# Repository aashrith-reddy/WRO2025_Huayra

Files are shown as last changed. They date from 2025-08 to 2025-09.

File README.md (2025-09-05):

## Team Members  
• Aashrith Chittamuru \
• Daksh Singh  \
• Vatsal Abrol 

**Coach**: \
• Mr.Kailash *(Roboprenr – Bangalore, India)*  

---

## Introduction
The **WRO2025_Huayra** project is a submission for the World Robot Olympiad (WRO) 2025 under the Future Engineers category. This initiative challenges participants to design, build, and program a self-driving vehicle that can navigate a dynamic environment autonomously. The project integrates mechanical design, embedded systems, and software engineering to create a robust autonomous platform. \
This report outlines the technical architecture, design methodology, software implementation, and theoretical underpinnings of the vehicle developed by Team Huayra.

---

## Project / Bot Description 
Our robot features a **rigid metal chassis reinforced with precision 3D-printed components**, ensuring durability. At its core, a **Raspberry Pi 5** orchestrates real-time processing for **laser sensors, a camera module, and a servo-driven steering system**, enabling highly accurate navigation and control. Its **low ground clearance, inspired by Formula 1 engineering principles, enhances stability and downforce**, ensuring superior performance during high-speed maneuvers. Designed with precision and reliability this platform is built to excel in the **WRO Future Engineers competition**.

---

## Table of Contents 
• **models**: contains .stl design files of all the 3d printed parts \
• **others**: contains additional documentation, such as Raspberry Pi setup and terminal usage guides, to help prepare the vehicle for the competition. \
• **schemes**: contains all the schematic diagrams and illustrates the functioning of the components used in the project \
• **src**: contains code for all components which were programmed for this competition. It also contains the final code for the competition \
• **videos**: includes two videos of the bot functioning \
• **vehicle-photos**: contains 6 photos of the bot (front, back, left, right, top, bottom) \
• **team-photos**: contains 2 images of our team (1 formal and 1 funny)

---

## Hardware Components

| Component | Description |
|---|---|
| Arduino Uno | Microcontroller for low-level sensor interfacing and motor control |
| Raspberry Pi | High-level processing unit for decision-making and image processing |
| Ultrasonic Sensors | Distance measurement for obstacle detection |
| Servo Motors | Steering mechanism |
| DC Motors with Encoders | Drive system with feedback for speed and position |
| Li-ion Battery Pack | Power source with voltage regulation |

## Software Stack

•  *Arduino IDE*: Used to program the microcontroller \
•  *Python (on Raspberry Pi)*: Handles image recognition, path planning, and serial communication \
•  *OpenCV*: For visual input processing and object detection

---

## Serial Communication Protocol

The  SerialCommunicationArduino.ino  file implements a custom protocol to facilitate reliable data exchange between the Arduino and Raspberry Pi. Key features include:

•  Baud rate synchronization at 9600 bps \
•  Real-time sensor data transmission

This protocol ensures deterministic behavior and low-latency control, critical for autonomous navigation.

---

## Mechanical Design

The chassis and structural components were designed with our critical thinking abilities using metal plates and CAD software and fabricated using 3D printing. The car's design was inspired from the old F1 cars from the early 2000's where the real wheels were bigger size than the front wheels as the rear drving system was built higher in the rear of the car than the front. STL files in the repository’s  models  folder provide the geometry for:

•  Wheel mounts \
•  Sensor brackets \
•  Battery housing \
•  Modular frame connectors

The design prioritizes weight distribution, accessibility, and modularity for quick maintenance and upgrades.

---

## Circuit Schematics

The  schemes  folder contains detailed circuit diagrams illustrating the integration of sensors, actuators, and controllers. These schematics follow best practices in embedded system design:

•  Insulating the metal base plates with tape to avoid short-circuiting \
•  Integration between arduino and Raspberry Pi 5 \
•  Fuse protection for motor drivers

---

## Control Algorithms

•  **Open Challenge**: Ultrasonic sensors detect the walls (boundaries) and the arduino adjusts motor speed as and when the car is turning or going straight. \
•  **Obstacle Avoidance**: Camera reaches a specific area limit of the color due to which it turns. \
•  **Parking Algorithm**: Uses Ultrasonic sensor feedback and servo positioning to execute parallel parking.

---

## Conclusion

The WRO2025_Huayra project reflects our team’s dedication to combining mechanical design, electronics, and advanced software algorithms into a single autonomous vehicle capable of tackling the dynamic challenges of the WRO Future Engineers competition. By leveraging the strengths of both the Arduino Uno and Raspberry Pi 5, we achieved a balance between low-level real-time control and high-level decision-making. Our focus on rigid mechanical design, robust sensor integration, and modular architecture ensures that the vehicle is not only competition-ready but also adaptable for future improvements.

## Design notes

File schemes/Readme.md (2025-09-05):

# Schemes Folder – Electromechanical Diagrams

This folder contains all schematic diagrams and layout illustrations for the entire project.

## Files

Each file provides visual context for the hardware and wiring.
1. `Design.md`
2. `Differential_Gearbox.md`
3. `Parts_List.md`

## Attachments

1. `CircuitDiagram.png` – Wiring map of Pi 5, sensors, camera, servo, motor driver, and power system.
2. `FirstLayer.png` – First layer showing steering system, servo, motor, battery, and gearbox.
3. `SecondLayer.png` – Top layer with Pi 5, cooling, buck converter, TOF sensors, and camera mount.
4. `ChassisSide.png` – Side view showing low clearance, stacked layers, and component layout.
5. `DifferentialGearbox_functioning.png` – Diagram of torque split between rear wheels during turns.
6. `DifferentialGearbox_parts.png` – Labeled schematic of all differential gearbox components.

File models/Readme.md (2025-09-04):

# 3D Models

This folder contains all the **3D design files** used in the construction of our competition robot.  

## Contents
Below is a list of all 3D-printed files included in this folder:

- **CouplerForGearbox.stl** – 3D design of the **Coupler** which connects the **Wheels** and the **Differential Gearbox**  
- **DifferentialHolder.stl** – 3D design for the **Differential Gearbox Holder**

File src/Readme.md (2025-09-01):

# Software Documentation

This repository contains **all modular scripts** used to build the final code. Below is a **script-by-script feature list** for the entire project:

---

### camera.py
```bash
from picamera2 import Picamera2
import cv2, time

cam = Picamera2()
cam.configure(cam.create_preview_configuration(main={"format":"RGB888","size":(640,480)}))
cam.start(); time.sleep(0.5)

while True:
    f = cam.capture_array()
    cv2.imshow("Feed", f)
    if cv2.waitKey(1)&0xFF==ord('q'): break

cam.stop(); cv2.destroyAllWindows()
```

**1.	Imports required libraries** \
&nbsp;&nbsp;&nbsp;•	picamera2 to control Raspberry Pi Camera \
&nbsp;&nbsp;&nbsp;•	cv2 (OpenCV) to show frames in a window \
&nbsp;&nbsp;&nbsp;•	time for adding a small delay after starting the camera
```bash
from picamera2 import Picamera2
import cv2, time
```

**2.	Initializes the camera** \
&nbsp;&nbsp;&nbsp;•	Creates a Picamera2 object under the variable name cam. \
&nbsp;&nbsp;&nbsp;•	Configures it to output **640×480 frames** in **RGB888 format**.
```bash
cam = Picamera2()
cam.configure(cam.create_preview_configuration(main={"format":"RGB888","size":(640,480)}))
```
**3.	Starts the camera** \
&nbsp;&nbsp;&nbsp;•	Starts streaming frames. \
&nbsp;&nbsp;&nbsp;•	Waits 0.5 seconds to allow the sensor to stabilize.
```bash
cam.start(); time.sleep(0.5)
```
**4.	Main loop to display video** \
&nbsp;&nbsp;&nbsp;•	Displays them in a window titled “Feed”. \
&nbsp;&nbsp;&nbsp;•	Exits when the ‘q’ key is pressed.
```bash
while True:
    f = cam.capture_array()
    cv2.imshow("Feed", f)
    if cv2.waitKey(1)&0xFF==ord('q'): break
```
**5. Stops the camera** \
&nbsp;&nbsp;&nbsp;•	Stops the camera stream. \
&nbsp;&nbsp;&nbsp;•	Closes any OpenCV windows.
```bash
cam.stop(); cv2.destroyAllWindows()
```

---

### **TOFsensor.py**
```bash
import time
import board
import busio
from gpiozero import LED
from adafruit_vl53l0x import VL53L0X

xshut_pin = LED(17)
i2c = busio.I2C(board.SCL, board.SDA)
xshut_pin.off()
time.sleep(0.1)
xshut_pin.on()
time.sleep(0.1)
sensor = VL53L0X(i2c)

try:
    while True:
        distance = sensor.range /10
        print(f"Distance: {distance} cm")
        time.sleep(1)
except KeyboardInterrupt:
    print("Program stopped")
```

**1. Imports required libraries** \
&nbsp;&nbsp;&nbsp;•	time — used for adding short delays. \
&nbsp;&nbsp;&nbsp;•	board — maps Raspberry Pi pins (SCL, SDA, etc.) for I²C communication. \
&nbsp;&nbsp;&nbsp;•	busio.I2C — handles I²C protocol communication. \
&nbsp;&nbsp;&nbsp;•	gpiozero.LED — convenient way to control a GPIO pin as a simple on/off output (here, it’s used for XSHUT rather than an actual LED). \
&nbsp;&nbsp;&nbsp;•	adafruit_vl53l0x.VL53L0X — library to talk to the VL53L0X time-of-flight distance sensor.
```bash
import time
import board
import busio
from gpiozero import LED
from adafruit_vl53l0x import VL53L0X
```

**2. Hardware Setup** \
&nbsp;&nbsp;&nbsp;•	xshut_pin is GPIO17 configured as an output using gpiozero’s LED class. \
&nbsp;&nbsp;&nbsp;&nbsp;&nbsp;&nbsp;•	Even though it’s called LED, it’s just a digital output that can be turned on/off. \
&nbsp;&nbsp;&nbsp;&nbsp;&nbsp;&nbsp;•	This pin is connected to the XSHUT (shutdown) pin of the VL53L0X sensor. \
&nbsp;&nbsp;&nbsp;•	i2c = busio.I2C(board.SCL, board.SDA) sets up the I²C bus using the Pi’s hardware SCL and SDA pins.
```bash
xshut_pin = LED(17)
i2c = busio.I2C(board.SCL, board.SDA)
```

**3. Reset the sensor using XSHUT** \
&nbsp;&nbsp;&nbsp;•	xshut_pin.off() drives GPIO17 low due to which VL53L0X is held in reset (powered off). \
&nbsp;&nbsp;&nbsp;•	Wait 0.1 s for it to fully power down. \
&nbsp;&nbsp;&nbsp;•	xshut_pin.on() drives GPIO17 high due to which VL53L0X powers up again. \
&nbsp;&nbsp;&nbsp;•	Wait another 0.1 s for the sensor to initialize. \ \

&nbsp;&nbsp;&nbsp;This reset sequence ensures the sensor is in a clean state, and is especially useful when you have multiple sensors on the same I²C bus &nbsp;&nbsp;&nbsp;(you can power them up one at a time and give them unique addresses).
```bash
xshut_pin.off()
time.sleep(0.1)
xshut_pin.on()
time.sleep(0.1)
```

**4. Create the sensor object** \
&nbsp;&nbsp;&nbsp;•	Initializes the Adafruit VL53L0X driver on the I²C bus. \
&nbsp;&nbsp;&nbsp;•	The library automatically uses the default address 0x29 unless you change it.
```bash
sensor = VL53L0X(i2c)
```

**5. Main Loop** \
&nbsp;&nbsp;&nbsp;•	sensor.range returns distance in millimeters (mm). \
&nbsp;&nbsp;&nbsp;•	Dividing by 10 converts to centimeters (cm). \
&nbsp;&nbsp;&nbsp;•	Prints out the distance every 1 second.
```bash
try:
    while True:
        distance = sensor.range / 10
        print(f"Distance: {distance} cm")
        time.sleep(1)
```

**6. Exit** \
&nbsp;&nbsp;&nbsp;•	If you press Ctrl + C, the loop ends and prints a message.
```bash
except KeyboardInterrupt:
    print("Program stopped")
```

---

### **Steering.py**
```bash
from rpi_hardware_pwm import HardwarePWM
from time import sleep

pwm = HardwarePWM(pwm_channel=0, hz=50, chip=0)
pwm.start(5)

try:
    while True:
        pwm.change_duty_cycle(5)
        sleep(2)
        pwm.change_duty_cycle(7.5)
        sleep(2)
        pwm.change_duty_cycle(9.7)
        sleep(2)
        pwm.change_duty_cycle(7.5)
        sleep(2)

except KeyboardInterrupt:
    pwm.stop()
```
**1. Imports Required Libraries** \
&nbsp;&nbsp;&nbsp;•	rpi_hardware_pwm.HardwarePWM lets you control the Pi’s built-in hardware PWM channels. Hardware PWM is more stable and jitter-&nbsp;&nbsp;&nbsp;free than software PWM (like in RPi.GPIO), which is especially important for servos. \
&nbsp;&nbsp;&nbsp;•	sleep() pauses the program for a specified time in seconds.
```bash
from rpi_hardware_pwm import HardwarePWM
from time import sleep
```
**2. Create PWM object** \
&nbsp;&nbsp;&nbsp;•	pwm_channel=0 — uses hardware PWM channel 0 (the Pi has two: 0 and 1). \
&nbsp;&nbsp;&nbsp;•	hz=50 — sets frequency to 50 Hz (period = 20 ms), standard for servo motors. \
&nbsp;&nbsp;&nbsp;•	chip=0 — refers to /sys/class/pwm/pwmchip0, the first hardware PWM controller on the Pi.
```bash
pwm = HardwarePWM(pwm_channel=0, hz=50, chip=0)
```
**3. Start PWM with 5% duty cycle** \
&nbsp;&nbsp;&nbsp;•  This enables PWM output on that channel with a duty cycle of 5% (i.e., the signal is HIGH for 1 ms and LOW for 19 ms, since 20 ms &nbsp;&nbsp;&nbsp;period × 5% = 1 ms). \
&nbsp;&nbsp;&nbsp;•	For a hobby servo: \
&nbsp;&nbsp;&nbsp;&nbsp;&nbsp;&nbsp;•	~5% → far left position (~0°) \
&nbsp;&nbsp;&nbsp;&nbsp;&nbsp;&nbsp;•	~7.5% → center (~90°) \
&nbsp;&nbsp;&nbsp;&nbsp;&nbsp;&nbsp;•	~10% → far right (~180°)
```bash
pwm.start(5)
```
**4. Main Loop** \
&nbsp;&nbsp;&nbsp;•	5% → servo moves to left position \
&nbsp;&nbsp;&nbsp;•	7.5% → servo centers \
&nbsp;&nbsp;&nbsp;•	9.7% → servo moves to right position \
&nbsp;&nbsp;&nbsp;•	7.5% → servo centers again

**5. Exit** \
&nbsp;&nbsp;&nbsp;•	When you press Ctrl + C, the program exits the loop. \
&nbsp;&nbsp;&nbsp;•	pwm.stop() disables PWM output so the pin no longer outputs a PWM signal.
```bash
except KeyboardInterrupt:
    pwm.stop()
```

---

### **MotorDriver.py**
```bash
from gpiozero import DigitalOutputDevice
from rpi_hardware_pwm import HardwarePWM
from time import sleep

direction = DigitalOutputDevice(17)
pwm = HardwarePWM(pwm_channel=1, hz=18000, chip=0)

try:
    direction.value = 1
    pwm.start(30)
    print("Motor running forward at 30%...")
    sleep(5)

    pwm.stop()
    print("Motor stopped.")
    sleep(1)

    direction.value = 0
    pwm.start(30)
    print("Motor running backward at 30%...")
    sleep(5)

    pwm.stop()
    print("Motor stopped.")

except KeyboardInterrupt:
    print("Interrupted by user.")
    pwm.stop()
```
**1. Imports required Libraries** \
&nbsp;&nbsp;&nbsp;•	DigitalOutputDevice (gpiozero) — lets you easily set a GPIO pin HIGH or LOW to control directio \
&nbsp;&nbsp;&nbsp;•	HardwarePWM (rpi_hardware_pwm) — generates a very stable PWM signal directly using the Pi’s hardware \
&nbsp;&nbsp;&nbsp;•	sleep: Used to pause execution for a given number of seconds.
```bash
from gpiozero import DigitalOutputDevice
from rpi_hardware_pwm import HardwarePWM
from time import sleep
```
**2. Hardware setup** \
&nbsp;&nbsp;&nbsp;•	direction → GPIO17 controls the motor’s rotation direction. \
&nbsp;&nbsp;&nbsp;•	pwm → hardware PWM on channel 1 at 18 kHz frequency. \
&nbsp;&nbsp;&nbsp;&nbsp;&nbsp;&nbsp;•	18 kHz is above human hearing which means that no audible whining from the motor would be heard.
```bash
direction = DigitalOutputDevice(17)
pwm = HardwarePWM(pwm_channel=1, hz=18000, chip=0)
```
**3. Main Loop** \
&nbsp;&nbsp;&nbsp;•	direction.value: \
&nbsp;&nbsp;&nbsp;&nbsp;&nbsp;&nbsp;• =1 → sets GPIO17 HIGH which makes the motor driver rotate the motor forward. \
&nbsp;&nbsp;&nbsp;&nbsp;&nbsp;&nbsp;• =0 → sets GPIO17 LOW which makes the motor driver rotate the motor backward. \
&nbsp;&nbsp;&nbsp;•	pwm.start(30) → starts PWM with 30% duty cycle, meaning the motor gets ~30% of its speed. \
&nbsp;&nbsp;&nbsp;•	sleep() → waits for an amount of time

**4. Exit** \
&nbsp;&nbsp;&nbsp;•	If you press Ctrl + C, the program exits and ensures PWM is stopped so the motor doesn’t keep running unexpectedly.
```bash
except KeyboardInterrupt:
    print("Interrupted by user.")
    pwm.stop()
```
---

### **ColorDetection.py**
```bash
import cv2
import numpy as np
from picamera2 import Picamera2

COLOR_RANGES = {
    "orange":  (np.array([5, 120, 120]),  np.array([22, 255, 255])),
    "blue":    (np.array([95, 80, 60]),   np.array([125, 255, 255])),
    "red1":    (np.array([0, 150, 80]),   np.array([10, 255, 255])),
    "red2":    (np.array([170,150,80]),   np.array([179,255,255])),
    "green":   (np.array([40, 80, 80]),   np.array([85, 255, 255])),
    "magenta": (np.array([140, 80, 80]),  np.array([170, 255, 255]))
}

picam2 = Picamera2()
config = picam2.create_preview_configuration(main={"size": (640, 480)})
picam2.configure(config)
picam2.start()

print("Press 'q' to quit")

while True:
    frame = picam2.capture_array()
    hsv = cv2.cvtColor(frame, cv2.COLOR_BGR2HSV)
    
    # Loop through colors and detect
    for color, (lower, upper) in COLOR_RANGES.items():
        if color == "red1":  
            # Special handling for red (two ranges)
            mask1 = cv2.inRange(hsv, COLOR_RANGES["red1"][0], COLOR_RANGES["red1"][1])
            mask2 = cv2.inRange(hsv, COLOR_RANGES["red2"][0], COLOR_RANGES["red2"][1])
            mask = cv2.bitwise_or(mask1, mask2)
            display_color = (0, 0, 255)
            label = "red"
        else:
            mask = cv2.inRange(hsv, lower, upper)
            if color == "orange":  display_color = (0, 140, 255)
            elif color == "blue": display_color = (255, 0, 0)
            elif color == "green": display_color = (0, 255, 0)
            elif color == "magenta": display_color = (255, 0, 255)
            label = color

        contours, _ = cv2.findContours(mask, cv2.RETR_EXTERNAL, cv2.CHAIN_APPROX_SIMPLE)
        for cnt in contours:
            area = cv2.contourArea(cnt)
            if area > 1000:  # filter noise
                x, y, w, h = cv2.boundingRect(cnt)
                cv2.rectangle(frame, (x, y), (x+w, y+h), display_color, 2)
                cv2.putText(frame, label, (x, y-10), cv2.FONT_HERSHEY_SIMPLEX, 0.6, display_color, 2)
    
    cv2.imshow("Color Detection", frame)
    if cv2.waitKey(1) & 0xFF == ord('q'):
        break

cv2.destroyAllWindows()
picam2.stop()
```
**1. Import required Libraries** \
&nbsp;&nbsp;&nbsp;•	cv2: for image processing, drawing, masking, contour detection, showing live video. \
&nbsp;&nbsp;&nbsp;•	numpy: for array operations and defining HSV color bounds. \
&nbsp;&nbsp;&nbsp;•	picamera2: to access Raspberry Pi Camera v1.3 on Raspberry Pi 5.
```bash
import cv2
import numpy as np
from picamera2 import Picamera2
```
**2. Define Color Ranges (in HSV)** \
&nbsp;&nbsp;&nbsp;•	A dictionary COLOR_RANGES stores lower and upper HSV limits for orange, blue, red, green, and magenta. \
&nbsp;&nbsp;&nbsp;•	Red uses two separate ranges (red1 and red2) because red appears at both ends of the hue scale. \
&nbsp;&nbsp;&nbsp;•	These ranges allow easy color filtering using OpenCV’s cv2.inRange() function. \

**3. Initialize the Raspberry Pi Camera** \
&nbsp;&nbsp;&nbsp;•	Create a Picamera2() instance. \
&nbsp;&nbsp;&nbsp;•	Configure it for preview at 640×480 resolution. \
&nbsp;&nbsp;&nbsp;•	Start the camera so frames can be captured continuously.
```bash
picam2 = Picamera2()
config = picam2.create_preview_configuration(main={"size": (640, 480)})
picam2.configure(config)
picam2.start()
print("Press 'q' to quit")
```
**4. Main Loop** \
&nbsp;&nbsp;&nbsp;• Capture each frame, convert it to HSV, detect colors, and draw bounding boxes \
&nbsp;&nbsp;&nbsp;•	inRange() creates a binary mask for each color. \
&nbsp;&nbsp;&nbsp;•	findContours() locates regions of that color. \
&nbsp;&nbsp;&nbsp;•	Bounding boxes and labels are drawn only if the blob is large enough (area > 1000).

**5. Display Results** \
&nbsp;&nbsp;&nbsp;•	imshow() opens a live video feed with detection boxes. \
&nbsp;&nbsp;&nbsp;•	waitKey(1) allows OpenCV to update the display and listen for keyboard input. \
&nbsp;&nbsp;&nbsp;•	Exits loop when q is pressed.
```bash
    cv2.imshow("Color Detection", frame)
    if cv2.waitKey(1) & 0xFF == ord('q'):
        break
```
**6. Cleanup** \
&nbsp;&nbsp;&nbsp;•	destroyAllWindows() closes any OpenCV GUI windows. \
&nbsp;&nbsp;&nbsp;•	stop() shuts down the Pi camera properly.
```bash
cv2.destroyAllWindows()
picam2.stop()
```
---

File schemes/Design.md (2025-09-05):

# Chassis and Structural Layout

The foundation of the robot is a **metal base plate**, which provides mechanical strength and rigidity to support all mounted subsystems. The bottom layer of this base is equipped with the **Steering System**, actuated by a **Servo motor** that precisely controls the angular orientation of the front wheels. This servo-based control enables accurate navigation and cornering, critical for path-following algorithms and obstacle avoidance. Positioned on the same bottom layer, the **motor** is connected to a **differential gearbox**, which is securely held in place by a **3D-printed holder**. The rear wheels are also attached to the gearbox using **3D-printed couplers**. Additionally, a **3D-printed camera stand** is placed on this bottom layer, located between the motor and the steering system. The 3D-models are present in the `models` folder.

A key design consideration is the robot’s **minimal ground clearance**, achieved through a **low-profile chassis configuration inspired by Formula 1 car engineering**. This design enhances **aerodynamic downforce**, improving **wheel-to-ground contact** during motion, resulting in significantly **increased stability**, particularly at higher speeds or during sharp directional transitions.

---
# Drive Mechanism

Located on the bottom layer, the motor serves as the **primary source** of **mechanical power** for the drivetrain. Its output shaft is **mechanically coupled to a differential gearbox**, held by a **3D-printed mount**, which splits torque between the two rear wheels. This allows each wheel to rotate at different speeds while receiving power from the same motor, a critical feature during turning maneuvers where inner and outer wheels travel different distances. The wheels are connected to the gearbox using **3D-printed couplers**, ensuring precise alignment and durability.

More about the differential gearbox is present in `Differential_Gearbox.md`.

---
# Battery Placement and Power Routing

On the bottom layer, four metallic spacers are mounted vertically at the rear corners and center, forming a platform to support a small metal plate on the next layer. This upper layer houses the **2500mAh Battery**, positioned to remain protected and thermally isolated from heat-generating components. The **wiring from the battery** is routed to the upper layer, which connects to the **motor as well as the arduino**. The battery efficiently regulates and distributes electrical power to the **Arduino Uno** and **motor**. The **Raspberry Pi 5** is powered by a **lithium ion 10000 Mah power bank** and are also placed on this upper layer, ensuring a compact and organized power management system.

---
# Sensor Configuration

The robot features a **three-sensor array** of **Ultrasonic sensors**, designed to optimize spatial awareness and real-time environmental perception. One sensor faces **directly forward**, providing accurate distance measurements along the primary axis of movement. The other two sensors are mounted at **45° angles** for the **open challenge round** forming a wide-angle, triangular sensing pattern and is mounted at **90° angles** for the **obstacle challenge round** to the **front-left** and **front-right** ensuring that it can sense all the walls in a correct manner. This configuration expands the robot’s **field of view**, enabling simultaneous obstacle detection, distance measurement, and angle estimation for approaching objects.

---
# Control Unit and Final Layer

The **topmost platform** hosts the **electronic control and processing unit**. The **Raspberry Pi 5**, located on the upper layer alongside the battery, powerbank and the arduino uno, serves as the **central processing unit (CPU)**, executing core decision-making algorithms. The **Arduino Uno** handles the ultrasonic sensors and gives commands that executes everything in place. A **5MP Raspberry Pi Camera Module**, mounted on a metal strip on the bottom layer, provides **real-time visual input** for vision-based functions like obstacle and color detection.

---
# Pictures

1. First Layer  
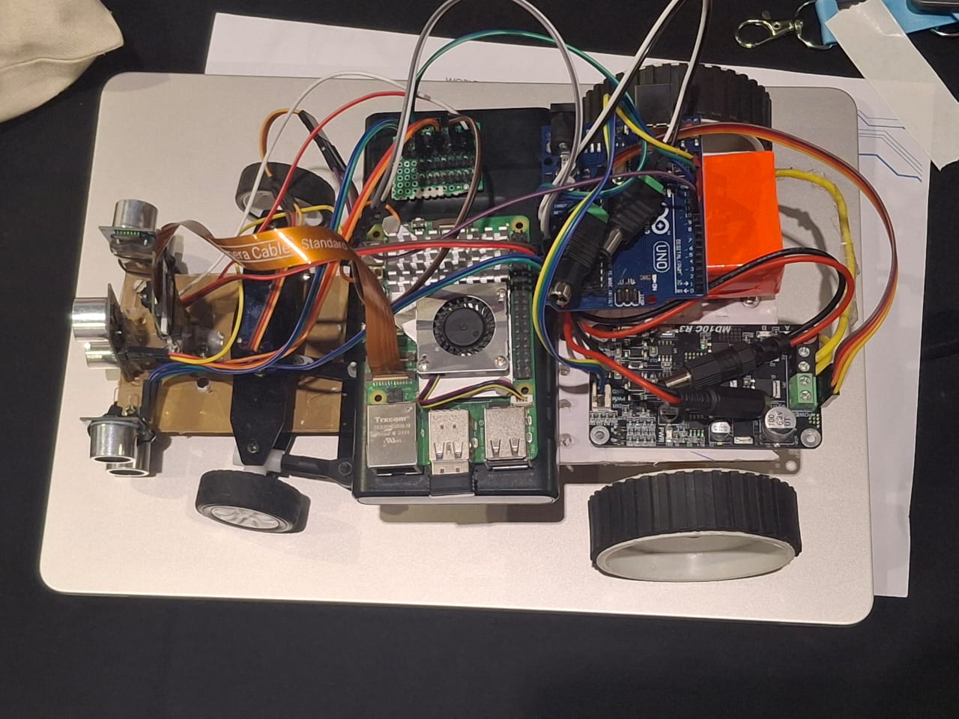
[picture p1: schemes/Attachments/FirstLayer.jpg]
  
2. Second Layer  
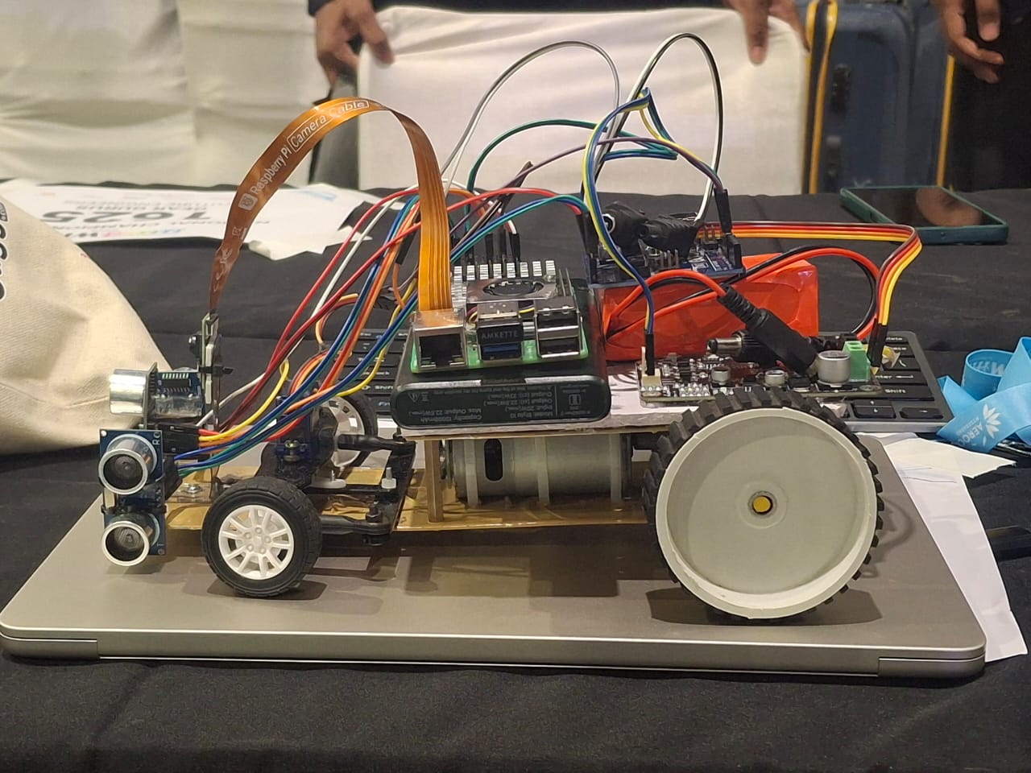
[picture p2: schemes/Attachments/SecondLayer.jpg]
  
3. Circuit Diagram  
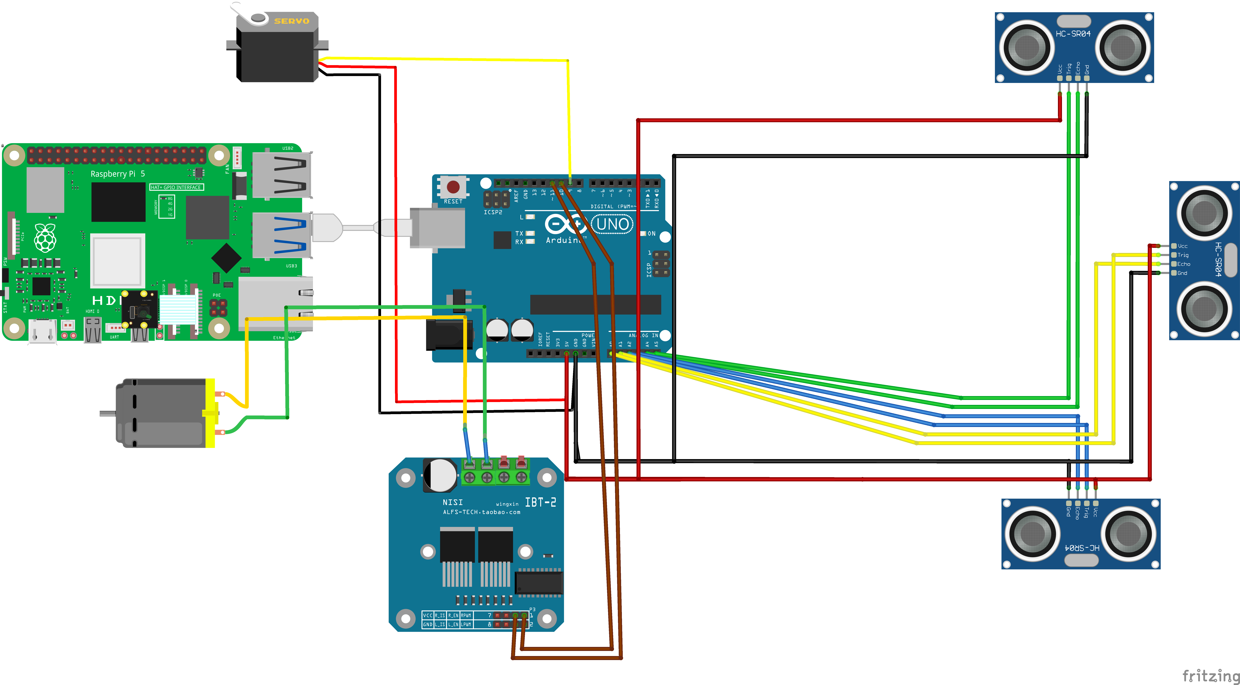
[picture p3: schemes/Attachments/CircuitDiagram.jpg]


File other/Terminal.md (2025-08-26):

# Raspberry Pi Dependencies Installation Guide

This document describes how to set up all required system dependencies, Python libraries, and interfaces on a Raspberry Pi 5 (or any Raspberry Pi running Raspberry Pi OS) using the terminal.

---

**1. Update System**
```bash
  sudo apt update
  sudo apt upgrade -y
```
**2. Install System Dependencies via apt**
```bash
    sudo apt install -y \
    python3-opencv \
    python3-pip \
    python3-picamera2 \
    python3-numpy \
    python3-smbus \
    python3-pigpio \
    python3-rpi.gpio \
```
**3. Creating a Virtual Environment and installing all required packages via pip**
    
```bash
    python3 -m venv venv
    source venv/bin/activate
```
```bash
    pip3 install \
    adafruit-circuitpython-vl53l0x \
    RPi.GPIO \
    pigpio \
    numpy \
    opencv-python \
    opencv-contrib-python \
    picamera2
```
When you are finished working within the virtual environment, you can deactivate it and return to the global Python environment by typing:
```bash
    deactivate
```

**4. Enabling Camera Interface**

   Enable hardware interfaces using raspi-config:
```bash
  sudo raspi-config
```
Navigate through: Interface Options → Enable Camera

**5. Start pigpio Daemon**

    The pigpio daemon must be running for motor control and steering systems:
```bash
    sudo systemctl enable pigpiod
    sudo systemctl start pigpiod
```

**6. Verification**

   To check if installations succeeded:
   ```bash
    python3 -c "import cv2, picamera2, smbus2, RPi.GPIO, pigpio; print('All dependencies installed successfully!')"
   ```

---

**Reboot your Raspberry Pi after enabling these options by running the following:**
```bash
sudo reboot
```

---

### (OPTIONAL) Adjusting the Raspberry Pi 5 Fan's Minimum Temperature

To adjust the minimum temperature at which your Raspberry Pi 5's fan starts, you need to edit the **`config.txt`** file. This file contains various configuration settings for your Pi. You should **not** attempt to modify `.dtb` files, as they are compiled and not meant for manual editing.

---

**Step 1: Accessing the `config.txt` File**

  The configuration file is located at `/boot/firmware/config.txt`. You can edit it using a text editor like `nano`. Open a terminal and run the following command to begin editing:

```bash
  sudo nano /boot/firmware/config.txt
```
**Step 2: Modifying the Fan Settings**

  Once the file is open, you can add or modify the parameters related to the fan's behavior. These parameters are documented in the README file located at /boot/firmware/overlays/README, but remember not to edit the README file itself.
The key parameters for the fan's first cooling level are:
  1. fan_temp0: The temperature threshold (in millicelsius) for the fan to turn on. The default is 50,000 mC (50°C).
  2. fan_temp0_hyst: The temperature hysteresis (in millicelsius). The fan will turn off when the temperature drops fan_temp0_hyst below fan_temp0. The default is 5,000 mC (5°C).
  3. fan_temp0_speed: The fan's PWM speed setting, a value between 0 and 255. The default is 75.

To change the fan's minimum operating temperature, you should add the following lines to the end of your config.txt file. These settings will start the fan at 20°C and turn it off at 10°C.

```Bash
  dtparam=fan_temp0=20000
  dtparam=fan_temp0_hyst=10000
  dtparam=fan_temp0_speed=125
```

**Step 3: Saving and Exiting**

  After adding the lines, save the file by pressing Ctrl + X, then Y to confirm, and finally Enter. The changes will take effect after you reboot your Raspberry Pi.

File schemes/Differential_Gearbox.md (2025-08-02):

# Introduction  
  
A **differential gearbox** is a mechanical system that allows two output shafts to rotate at different speeds while receiving power from a common input. In our robot, it plays a critical role in enabling smooth cornering. The differential gearbox is connected to a motor, which provides the torque input. The gearbox then distributes this torque to two wheels, allowing for coordinated but variable-speed rotation depending on the robot’s direction of movement.  
  
# Mechanical Role  
  
When a robot turns, the wheel on the outside of the curve needs to rotate faster than the inner wheel. Without a differential, both wheels would be forced to rotate at the same speed, causing slippage, inefficient motion, and wear. By using a **differential gearbox**, the robot:  
1. Preserves traction and wheel alignment  
2. Minimizes motor load  
3. Increases maneuverability  
4. Prevents component strain during turns  
  
The gearbox’s placement after the motor and beside the wheels ensures that torque is split correctly, even during dynamic directional changes.  
  
# Explanation of Each Part(Image[1])  
  
**1. Differential Case (Central Casing)**  
  
The metallic housing, centrally located, serves as a crucial component that encases internal gears, such as spider gears. Its primary function is to efficiently transfer the input rotation to the entire internal gear system. This housing is designed to rotate synchronously with the input shaft, and it also supports and carries the ring gear.  
  
**2. Bevel Ring Gear**  
  
The ring gear, a larger toothed gear, is directly connected to the differential case. Its essential role is to receive power transmitted from the motor and then transfer this power to the differential case. This transfer of rotation to the ring gear in turn causes the entire differential assembly to spin, initiating the movement of the vehicle's wheels.  
  
**3. Axle Shafts (Left and Right Output Shafts)**  
  
The axle shafts are long, splined rods extending from both sides of the differential. Their crucial purpose is to transmit power from the internal spider gears directly to each wheel. During normal straight-line driving, both axle shafts rotate at equal speeds. However, when the vehicle navigates a turn, the differential allows the axle shafts to rotate at different speeds, accommodating the varying distances each wheel must travel. In our project, we will use a coupler, the 3d design of which is provided in the `models` section as `CouplerForGearbox.stl`
  
**4. Side Gears & Spider Gears**  
  
Spider gears are vital for the differential's function. Typically consisting of two or four small bevel gears, they are positioned on a perpendicular axis and mesh with the side gears, which are connected to the axle shafts. Their essential purpose is to enable the output shafts to rotate independently while continuously receiving power. This intricate system is what allows one wheel to rotate faster than the other, particularly when the vehicle is cornering.  
  
# Conclusion  
  
The output shafts of the differential gearbox are connected to two wheels. These wheels are mounted on the rear axle. When driving straight, both wheels receive equal torque and rotate at the same speed. When turning, the gearbox compensates automatically by allowing one wheel to rotate faster than the other.  
  
# Images  
  
1. Parts of a Differential Gearbox  
  
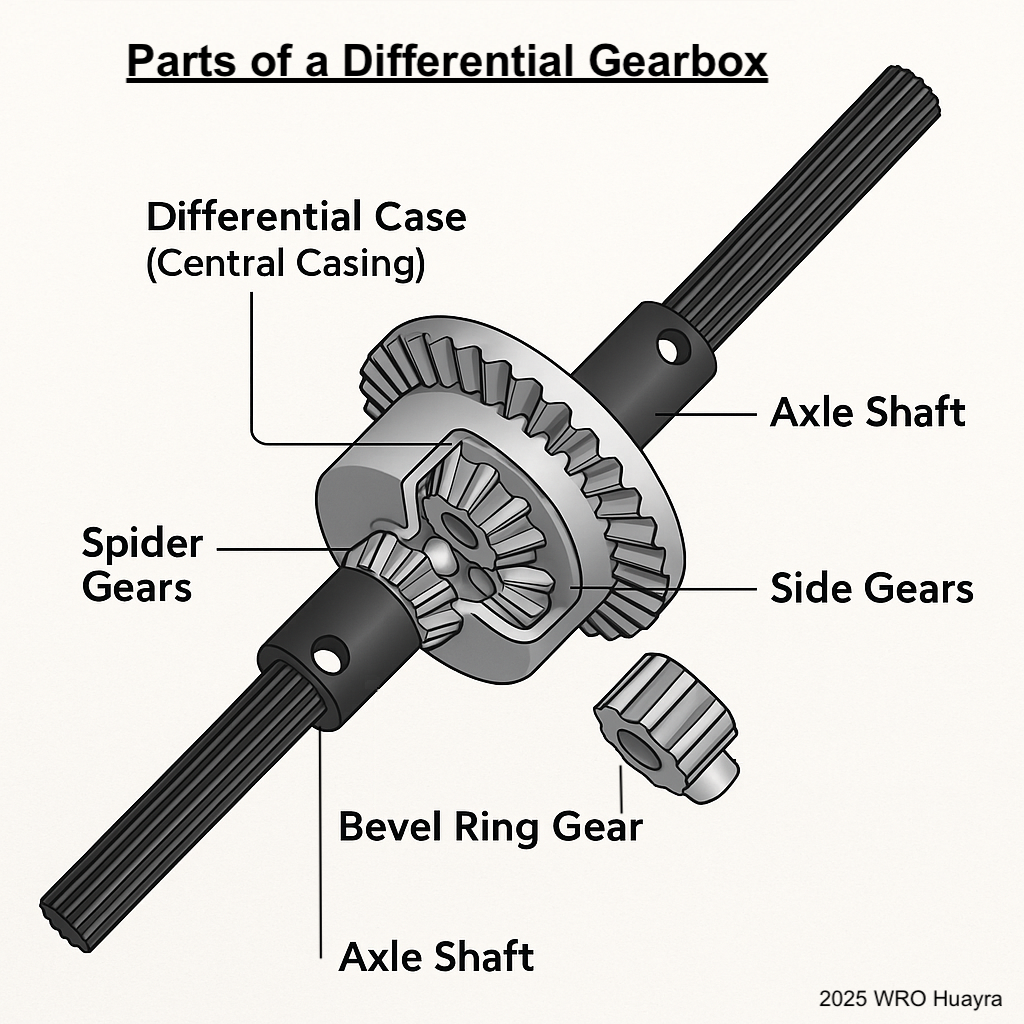
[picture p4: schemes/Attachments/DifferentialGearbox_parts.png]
Parts of a Differential Gearbox
  
  
2. Functioning of a Differential Gearbox  

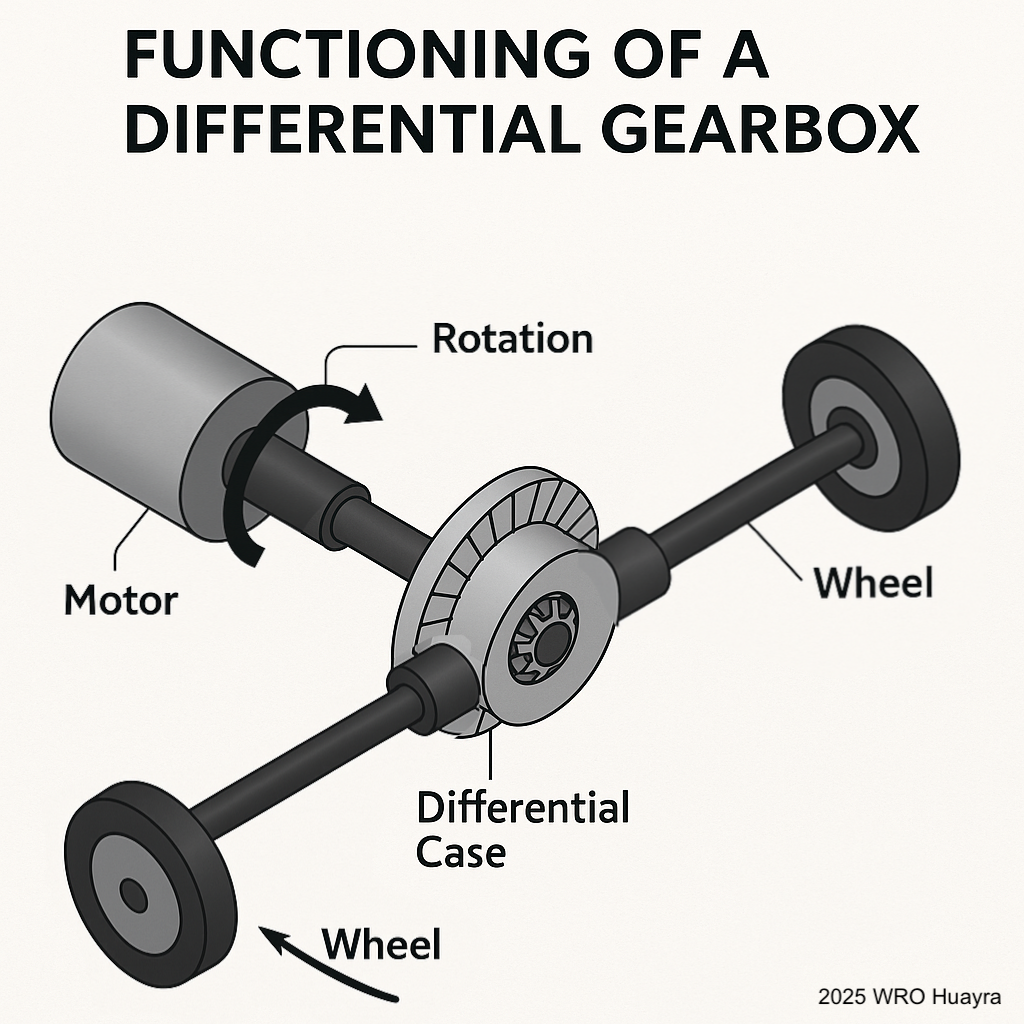
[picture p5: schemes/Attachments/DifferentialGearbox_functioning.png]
Functioning of a Differential Gearbox


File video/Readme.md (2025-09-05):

# Videos

This folder contains a document with links to videos showcasing our robot's performance in two **WRO Future Engineers challenges**:

## Contents
- **OpenChallengeVideo.mp4** – Demonstrates our robot’s performance in the open challenge.  
- **ObstacleChallengeVideo.mp4** – Demonstrates our robot’s navigation and collision avoidance in the obstacle course.

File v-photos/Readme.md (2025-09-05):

# Vehicle Photos

This folder contains six images of our competition robot, captured from all major angles to provide a complete visual reference.

## Contents
- **Top View** – `top.jpg`  
- **Front View** – `front.jpg`
- **Rear View** – `rear.jpg`
- **Left View** – `left.jpg`  
- **Right View** – `right.jpg`

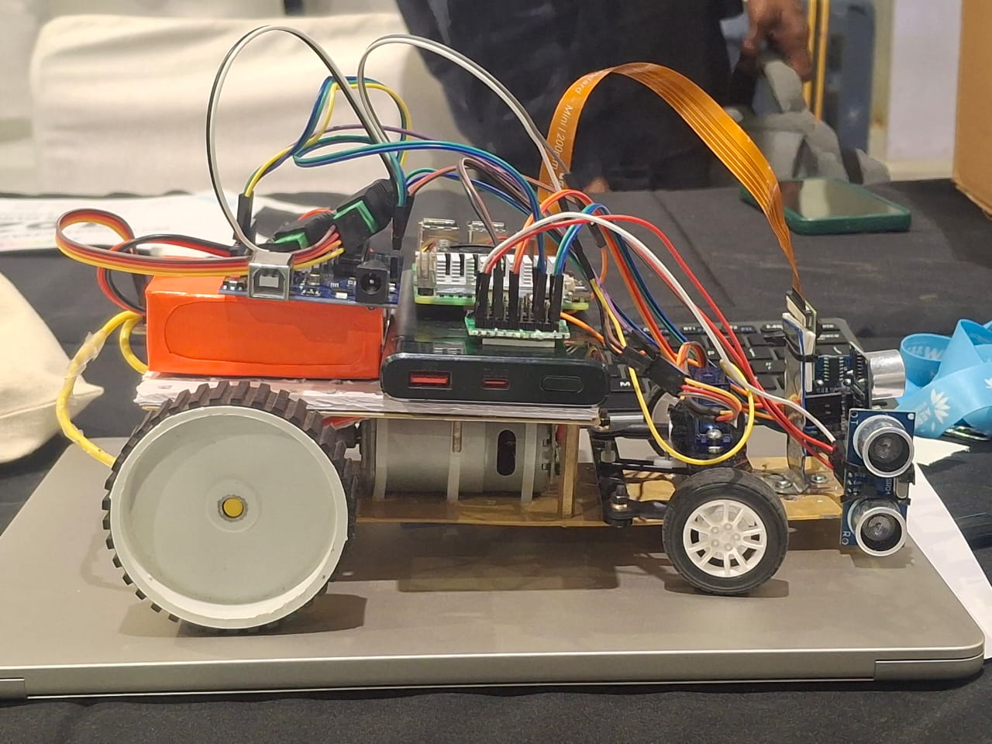
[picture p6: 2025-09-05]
schemes/Attachments/ChassisSide.jpg

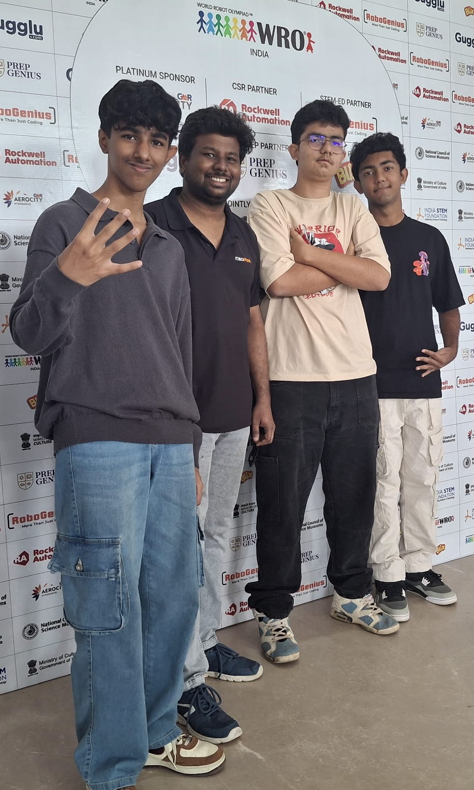
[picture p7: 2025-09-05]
t-photos/FunnyPhoto.jpeg

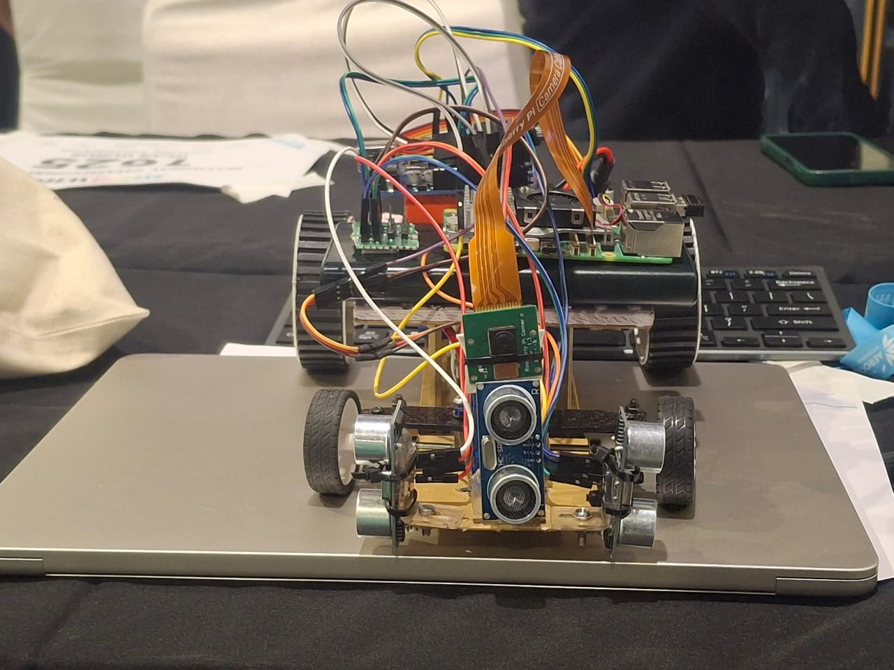
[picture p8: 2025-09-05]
v-photos/front.jpeg

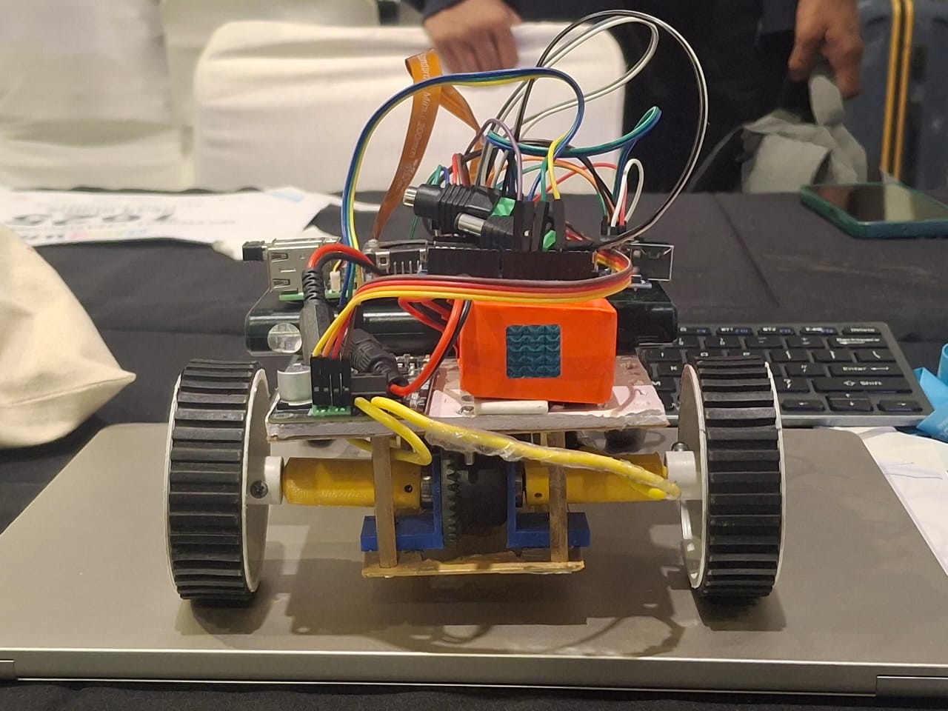
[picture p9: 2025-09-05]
v-photos/rear.jpeg

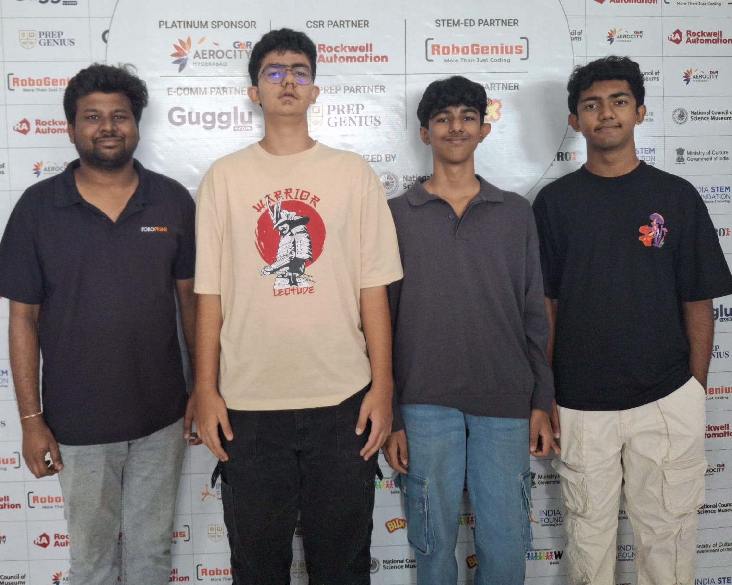
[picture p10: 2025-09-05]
t-photos/OfficialPhoto.jpeg

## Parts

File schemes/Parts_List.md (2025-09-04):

# Introduction  
  
The robot is built using a diverse set of electronic components, centered around the Raspberry Pi 5 as its primary processing unit. It features a custom DIY 2X2 steering system, and a motor connected to a differential gearbox (*A detailed document illustrating the system’s operation and mechanics is provided in `Differential_Gearbox.md`.*) to handle the drive mechanism. Power is sourced from a 7.4V 1000mAh 30C 2S LiPo battery, and an XL4015 step-down buck module. For visual input, the robot employs a 5MP Raspberry Pi Camera Module Rev 1.3, and is actively cooled using an official Pi 5 case fan. It also integrates a VL53L0X TOF-based LIDAR sensor for distance measurement.  
  
# List of Components  
  
1. Raspberry Pi 5: [https://robu.in/product/raspberry-pi-5-model-8gb/](https://robu.in/product/raspberry-pi-5-model-8gb/)  
2. Raspberry Pi 5 Official Cooler: [https://robu.in/product/official-raspberry-pi-5-active-cooler/](https://robu.in/product/official-raspberry-pi-5-active-cooler/)  
3. Raspberry Pi Camera: [https://robu.in/product/raspberry-pi-camera-module/](https://robu.in/product/raspberry-pi-camera-module/)  
4. LIDAR Laser Distance Sensor: [https://sharvielectronics.com/product/vl53l0x-tof-based-lidar-laser-distance-sensor/](https://sharvielectronics.com/product/vl53l0x-tof-based-lidar-laser-distance-sensor/)  
5. Battery: [https://robu.in/product/pro-range-1000mah-2s-30c60c-lithium-polymer-battery-pack-lipo/](https://robu.in/product/pro-range-1000mah-2s-30c60c-lithium-polymer-battery-pack-lipo/)  
6. Power Distributer: [https://robu.in/product/pdb-xt60-w-bec-5v-12v/](https://robu.in/product/pdb-xt60-w-bec-5v-12v/)  
7. Step Down Buck Module: [https://robu.in/product/xl4015-5a-dc-dc-step-down-adjustable-power-supply-buck-module-led-with-heatsink/](https://robu.in/product/xl4015-5a-dc-dc-step-down-adjustable-power-supply-buck-module-led-with-heatsink/)  
8. Compact Charger: [https://robu.in/product/b3ac-compact-balance-charger-2s-3s-lipo/](https://robu.in/product/b3ac-compact-balance-charger-2s-3s-lipo/)  
9. Steering System: [https://hubtronics.in/diy-zx2-steering-system-car-model](https://hubtronics.in/diy-zx2-steering-system-car-model)  
10. Motor: [https://www.amazon.in/gp/product/B0F1CL82KZ/ref=ox_sc_act_title_1?th=1](https://www.amazon.in/gp/product/B0F1CL82KZ/ref=ox_sc_act_title_1?th=1)  
11. 65 mm wheels (2x): https://www.electronicscomp.com/robot-wheel-65mm-dia-x-40mm-width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
12. Differential Gearbox: [https://www.amazon.in/Mirana-Spectre-4WD-Accessories-Differential/dp/B0F1CQ1T1R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](https://www.amazon.in/Mirana-Spectre-4WD-Accessories-Differential/dp/B0F1CQ1T1R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)  
13. SanDisk microSDXC: [https://amzn.in/d/bqYYjue](https://amzn.in/d/bqYYjue)
14. Arduino R3: https://robu.in/product/arduino-uno-r3/

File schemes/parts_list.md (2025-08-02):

# Introduction  
  
The robot is built using a diverse set of electronic components, centered around the Raspberry Pi 5 as its primary processing unit. It features a custom DIY 2X2 steering system, and a motor connected to a differential gearbox (*A separate document will contain detailed images of the system’s operation and mechanics.*) to handle the drive mechanism. Power is sourced from a 7.4V 1000mAh 30C 2S LiPo battery, and an XL4015 step-down buck module. For visual input, the robot employs a 5MP Raspberry Pi Camera Module Rev 1.3, and is actively cooled using an official Pi 5 case fan. It also integrates a VL53L0X TOF-based LIDAR sensor for distance measurement.  
  
# List of Components  
  
1. Raspberry Pi 5: [https://robu.in/product/raspberry-pi-5-model-8gb/](https://robu.in/product/raspberry-pi-5-model-8gb/)  
2. Raspberry Pi 5 Official Cooler: [https://robu.in/product/official-raspberry-pi-5-active-cooler/](https://robu.in/product/official-raspberry-pi-5-active-cooler/)  
3. Raspberry Pi Camera: [https://robu.in/product/raspberry-pi-camera-module/](https://robu.in/product/raspberry-pi-camera-module/)  
4. LIDAR Laser Distance Sensor: [https://sharvielectronics.com/product/vl53l0x-tof-based-lidar-laser-distance-sensor/](https://sharvielectronics.com/product/vl53l0x-tof-based-lidar-laser-distance-sensor/)  
5. 1000mAh Battery: [https://robu.in/product/pro-range-1000mah-2s-30c60c-lithium-polymer-battery-pack-lipo/](https://robu.in/product/pro-range-1000mah-2s-30c60c-lithium-polymer-battery-pack-lipo/)  
6. Power Distributer: [https://robu.in/product/pdb-xt60-w-bec-5v-12v/](https://robu.in/product/pdb-xt60-w-bec-5v-12v/)  
7. Step Down Buck Module: [https://robu.in/product/xl4015-5a-dc-dc-step-down-adjustable-power-supply-buck-module-led-with-heatsink/](https://robu.in/product/xl4015-5a-dc-dc-step-down-adjustable-power-supply-buck-module-led-with-heatsink/)  
8. Compact Charger: [https://robu.in/product/b3ac-compact-balance-charger-2s-3s-lipo/](https://robu.in/product/b3ac-compact-balance-charger-2s-3s-lipo/)  
9. Steering System: [https://hubtronics.in/diy-zx2-steering-system-car-model](https://hubtronics.in/diy-zx2-steering-system-car-model)  
10. Motor: [https://www.amazon.in/gp/product/B0F1CL82KZ/ref=ox_sc_act_title_1?th=1](https://www.amazon.in/gp/product/B0F1CL82KZ/ref=ox_sc_act_title_1?th=1)  
11. Differential Gearbox: [https://www.amazon.in/Mirana-Spectre-4WD-Accessories-Differential/dp/B0F1CQ1T1R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](https://www.amazon.in/Mirana-Spectre-4WD-Accessories-Differential/dp/B0F1CQ1T1R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)  
12. SanDisk microSDXC: [https://amzn.in/d/bqYYjue](https://amzn.in/d/bqYYjue)

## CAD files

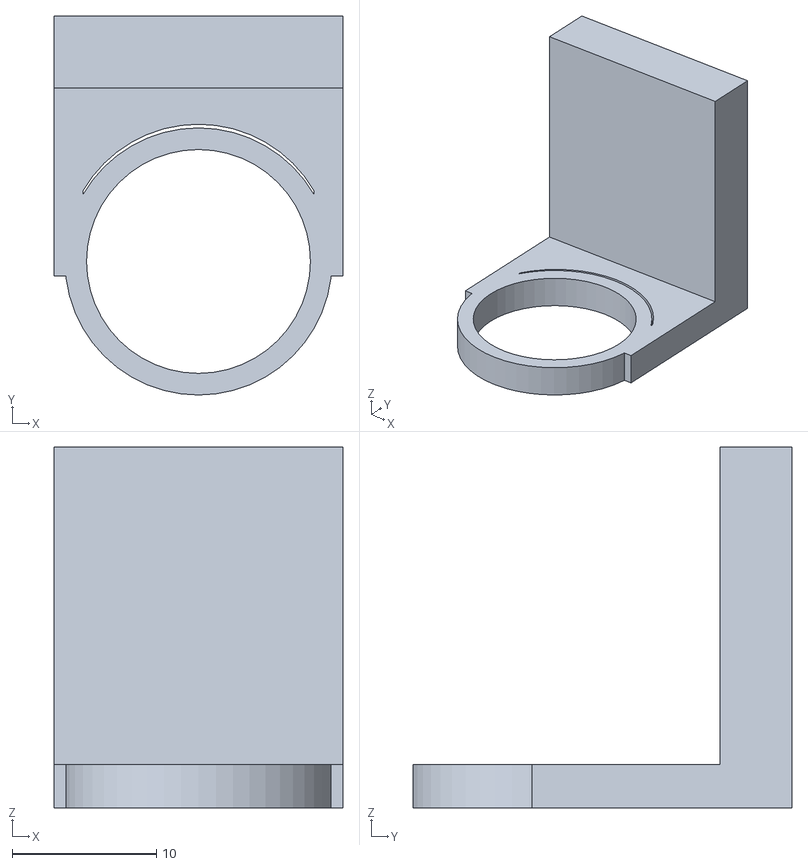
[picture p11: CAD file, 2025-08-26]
models/DifferentialHolder.stl
20.0 x 26.2 x 25.0

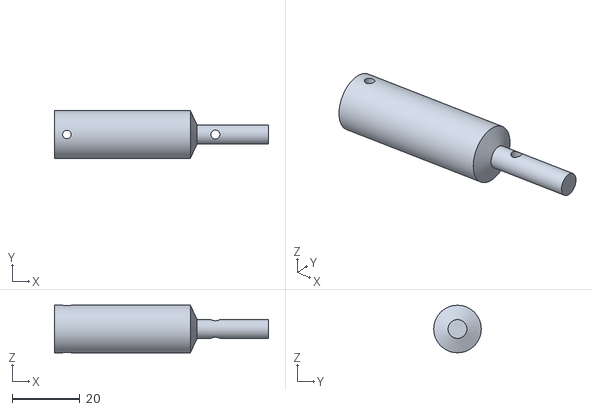
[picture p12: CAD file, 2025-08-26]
models/CouplorForGearbox.stl
63.0 x 14.0 x 14.0

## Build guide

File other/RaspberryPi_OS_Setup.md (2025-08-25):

# Raspberry Pi Software Installation Guide

This document describes **how we installed the Raspberry Pi OS on a SanDisk microSD card** for our project.  

---

## 1. Requirements

Before starting, ensure you have:
- **Raspberry Pi 5** (or other supported model)
- **microSD card** (at least 16GB)
- **microSD card reader** for your computer
- **Stable internet connection**
- **Power supply for the Pi (USB-C 5V/5A recommended)**
- **Keyboard, mouse, and HDMI monitor**

---

## 2. Download Raspberry Pi Imager

1. Go to the official Raspberry Pi download page:  
   [https://www.raspberrypi.com/software](https://www.raspberrypi.com/software)
2. Download **Raspberry Pi Imager** for your operating system:
   - Windows `.exe`
   - macOS `.dmg`
   - Linux `.deb` or `.AppImage`
3. Install and launch Raspberry Pi Imager.

---

## 3. Flash Raspberry Pi OS onto SanDisk microSD Card

1. Insert the **microSD card** into your card reader.  
2. Open **Raspberry Pi Imager**.  
3. Select **Operating System → Raspberry Pi OS (64-bit)** (Recommended).  
4. Select **Storage → Your microSD card**.  
6. Click **WRITE** and wait until it finishes verifying.

---

## 4. Boot the Raspberry Pi

1. Insert the **flashed microSD card** into the Raspberry Pi.  
2. Connect:
   - HDMI monitor
   - USB keyboard and mouse
   - Power supply
3. The Raspberry Pi should boot automatically into **Raspberry Pi OS desktop**.

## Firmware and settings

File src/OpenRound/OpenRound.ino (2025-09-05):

#include <Servo.h>

Servo steering;
const int servoPin = 9;
const int motorPWM = 11;
const int motorDir = 10;
const int trigLeft = A5;
const int echoLeft = A4;
const int trigRight = A3;
const int echoRight = A2;
const int trigCenter = A1;
const int echoCenter = A0;

void setup() {
  steering.attach(servoPin);
  pinMode(trigLeft, OUTPUT);
  pinMode(echoLeft, INPUT);
  pinMode(trigRight, OUTPUT);
  pinMode(echoRight, INPUT);
  pinMode(trigCenter, OUTPUT);
  pinMode(echoCenter, INPUT);
  pinMode(motorPWM, OUTPUT);
  pinMode(motorDir, OUTPUT);
  while (!Serial);
  Serial.println("Connected to Raspberry Pi");
}

void loop() {
  float distLeft = readUltrasonic(trigLeft, echoLeft);
  float distCenter = readUltrasonic(trigCenter, echoCenter);
  float distRight = readUltrasonic(trigRight, echoRight);
  if (Serial.available() > 0) {
    char input = Serial.read();
    digitalWrite(motorDir, LOW);
    analogWrite(motorPWM, 30);

    if (input=="S") {
      while(1);
      analogWrite(motorPWM, 0);
    else if (distRight>=200) {
      if (distCenter<=30) {
        analogWrite(motorPWM, 20);
        steering.write(135);
        delay(300);
        steering.write(90);
        analogWrite(motorPWM, 30);
      }    
    }
    else if (distLeft>=200) {
      if (distCenter<=30) {
        analogWrite(motorPWM, 20);
        steering.write(45);
        delay(300);
        steering.write(90);
        analogWrite(motorPWM, 30);
      }  
    }
  }
}

float readUltrasonic(int trigPin, int echoPin) {
  digitalWrite(trigPin, LOW);
  delayMicroseconds(20);
  digitalWrite(trigPin, HIGH);
  delayMicroseconds(100);
  digitalWrite(trigPin, LOW);
  float duration = pulseIn(echoPin, HIGH);
  return duration * 0.034 / 2.0;
}

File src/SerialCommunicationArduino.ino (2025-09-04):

void setup() {
  Serial.begin(9600);
  while (!Serial);
  Serial.println("Connected to Raspberry Pi");
}

void loop() {
  if (Serial.available() > 0) {
    char c = Serial.read();
    Serial.print("Got: ");
    Serial.println(c);
  }

  static unsigned long lastTime = 0;
  if (millis() - lastTime > 2000) {
    Serial.println("90201-TravisScott");
    lastTime = millis();
  }
}

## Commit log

2025-08-02 Rename Coupler for gearbox.stl to CouplerForGearbox.stl
    [CouplerForGearbox.stl]
2025-08-26 changed code for different motor driver
2025-08-26 Update Steering.py to use supported libraries
